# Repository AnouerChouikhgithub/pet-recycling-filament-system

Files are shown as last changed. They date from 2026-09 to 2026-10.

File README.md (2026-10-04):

# PET Plastic Recycling to 3D Printer Filament System

An Arduino-based system that turns PET plastic waste into usable 3D printer
filament through a custom-built extrusion control system. Independently
designed and developed as a solo project, currently in its 3rd hardware
iteration.

**Status:** Actively developed · 2024 – Present · Iterations V1 → V2 → V3 (V3.2 base assembly).

## Overview

The system controls extrusion temperature and filament feed rate in real time,
using closed-loop PID control and a microstepping stepper driver for consistent,
printable filament output. It is the machine side of the 3awedlou ecosystem:
the backend is the single backbone, and this firmware is the deterministic
controller that the ESP32 gateway will eventually network.

**Phases (as of this writing):**

| Phase | Description | Status |
|---|---|---|
| 1 | Arduino Mega direct control (Serial) | Done |
| 2 | ESP32 + TXS0108E serial gateway → MQTT | **Planned**, wired on bench, bench test pending |
| 3 | MQTT telemetry + command bridge to backend | Done (backend side, see repo README) |

This README documents the machine as it exists today (phase 1) and marks the
ESP32 gateway and the MQTT blade as planned. Hardware facts here come only from
the `.ino` and the files in `firmware/` and `cad/`; anything not present in the
code is marked `TODO(anouer)`.

## Repository tree (current)

```text
pet-recycling-filament-system/
├── firmware/
│   └── arduino-version/
│       └── arduino-version.ino          # Main Arduino firmware (PID control, stepper driving)
├── cad/
│   ├── PET-Recycling-Filament-System-Base - V3.2/
│   │   ├── PET-Recycling-Filament-System-Base 3.2.SLDPRT   # V3.2 base assembly, SolidWorks native
│   │   └── PET-Recycling-Filament-System-Base 3.2.STEP     # V3.2 base assembly, neutral STEP
│   └── 3D Printing/                  # Individual printable components (STEP)
│       ├── 2xBig-Separator.step
│       ├── 3xSmall-Separator.step
│       ├── 4xFixative.step
│       ├── Big-Gear-A.step
│       ├── Big-Gear-B.step
│       ├── Medium-Gear.step
│       ├── Medium-Separator.step
│       ├── Motor-Gear.step
│       ├── Motor-Separator.step
│       ├── Pulley.step
│       ├── Structure-A.step
│       └── Structure-B.step
├── docs/
│   ├── Schematic Diagram_bb.pdf      # Full breadboard / wiring schematic (Fritzing export)
└── README.md
```

> **Known stale paths in earlier READMEs:** the firmware is
> `firmware/arduino-version/arduino-version.ino` (NOT `firmware/code.ino`),
> the base assembly is `cad/PET-Recycling-Filament-System-Base - V3.2/`
> (NOT `cad/base-assembly/`). Keep this tree in mind when editing
> this document.

## Mechanical overview

The machine is a standalone PET extruder feeding a 3D printer filament path.
Base assembly and drivetrain are modeled in SolidWorks (`.SLDPRT`) plus a
neutral `.STEP` for interchange, and the printable cage/drivetrain parts are
provided as `.step` files in `cad/3D Printing/`.

| File / folder | What it is |
|---|---|
| `cad/PET-Recycling-Filament-System-Base - V3.2/` | Main structural assembly (V3.2), SolidWorks + STEP |
| `cad/3D Printing/*.step` | Individual 3D-printed parts: gears, separators, fixatives, pulleys, frame sections |
| `docs/Schematic Diagram_bb.pdf` | Full breadboard / wiring schematic |
| `firmware/arduino-version/arduino-version.ino` | Firmware source (single file) |

STEP files open in any CAD software (SolidWorks, Fusion 360, FreeCAD).

## Electronics overview

| Component | Role |
|---|---|
| Arduino Mega 2560 (with ATmega2560) | Main controller; keeps deterministic machine control |
| Thermistor (100 kΩ NTC, β=3950, nominal 25 °C @ 100 kΩ) | Temperature feedback for the PID loop, read on A7 |
| PWM-driven heater bridge (LPWM/RPWM) | Heating element actuation from the PID output |
| Stepper driver (TMC2209-class, 1/2–1/16 step) | Filament extrusion drive; microstepping selectable 1/2/4/8/16 via MS1–MS3 |
| Stepper motor (400 steps/rev full step) | Extrusion roller drive |
| Motor enable (R_EN/L_EN), Sleep/reset (SLEEP_RESET_PIN) | Driver enable + burst-mode wake |
| 12 V supply (heater + motor), 5 V (Arduino, thermistor) | Power rails; mains side is isolated from logic |

## Pin map (from `firmware/arduino-version/arduino-version.ino`)

Extracted verbatim from the sketch constants; nothing is inferred.

| Pin (Arduino name) | Constant name | Direction | Purpose | Source (`arduino-version.ino`) |
|---|---|---|---|---|
| 2 | `DIR_PIN` | OUTPUT | Motor direction (HIGH = reverse) | `setup()` / `loop()` |
| 3 | `STEP_PIN` | OUTPUT | Stepper step pulse | `loop()` |
| 4 | `SLEEP_RESET_PIN` | OUTPUT | Driver sleep/wake reset | `sleepDriver()` / `wakeDriver()` |
| 5 | `MS1_PIN` | OUTPUT | Microstepping select bit 1 | `setMicrostepping()` |
| 6 | `MS2_PIN` | OUTPUT | Microstepping select bit 2 | `setMicrostepping()` |
| 7 | `MS3_PIN` | OUTPUT | Microstepping select bit 3 | `setMicrostepping()` |
| 10 | `R_EN` | OUTPUT | H-bridge right side enable | `setHeaterPower()` / `heaterOff()` |
| 11 | `L_EN` | OUTPUT | H-bridge left side enable | `setHeaterPower()` / `heaterOff()` |
| 12 | `LPWM` | OUTPUT | Heater PWM (left H-bridge) | `setHeaterPower()` |
| 13 | `RPWM` | OUTPUT | Heater PWM (right H-bridge) | `setHeaterPower()` |
| A7 | `thermistorPin` | INPUT | Thermistor voltage divider ADC | `readingTemperature()` |

> `TODO(anouer): verify against the updated schematic` — the pin map above was
> read from the `.ino` only; the breadboard schematic (`docs/Schematic Diagram_bb.pdf`)
> has not been re-checked against the latest wired build.

## Firmware overview

### Control loop structure

`loop()` runs a tight, non-blocking cycle:

1. Read the thermistor (`readingTemperature()`).
2. Accelerate the motor: while `motorSpeed > MIN_MOTOR_DELAY`, decrement the
   step delay by `ACCELERATION_STEP` (5 µs per loop).
3. Drive the stepper: toggle `STEP_PIN` with `delayMicroseconds(motorSpeed)`
   and `delayMicroseconds(motorSpeed)` — a square wave whose period halves as
   speed ramps up.
4. Call `pidControl(temperature)`, which runs the PID on `millis()` deltas and
   scales the heater PWM.

The stepper timing loop is **independent** of the PID loop: stepping is
delay-based (not interrupt-driven), and PID runs in the same `loop()` pass.

### PID and units

* Target: `targetTemp = 245.0 °C` (PET extrusion).
* PID constants: `Kp = 5.0`, `Ki = 0.1`, `Kd = 30.0`.
* Output: `constrain(output, 0, 235)` → `setHeaterPower((int)output)` drives
  `LPWM` (left side enabled), `RPWM` holds at 0, both with `analogWrite` PWM.
* Temperature read over a 100 kΩ pull-up: `R = 100 kΩ`, β = 3950, nominal 25 °C,
  10-bit ADC, 5 V reference.

### Timing

* Stepper step time: `motorSpeed` in **microseconds** (starts 1000 µs, decrements
  toward `MIN_MOTOR_DELAY` = 200 µs, i.e. 5 k steps/s flat).
* PID runs on `millis()` deltas; `lastTime` seeded in `setup()`.

### Serial output

The firmware prints to `Serial` (baud 9600):

* `Serial.println("Setup complete. Driver awake, motor starting...")` in `setup()`.
* `Serial.print("Temp stable: ")` / `Serial.println(" °C")` when `|error| < 1.0`.
* `setMicrostepping()` prints the selected `1/n` mode.

No structured JSON, no `deviceAcknowledged`, and no command-response handshake
exist today. Serial is informational only.

### Safety status (as the code is written today)

| Check | Status |
|---|---|
| Over-temperature cutoff (hard >245 °C guard) | **Not implemented** as a hard cutoff. `pidControl` *clips* PID output to `constrain(output, 0, 235)` and turns the heater off if `temp > 330` or `temp == -273.15`; there is no independent over-temperature kill switch. |
| Thermistor fault handling | **Partially present.** `voltage <= 0` returns `-273.15`; `pidControl` then stops the heater. Clock drift / open-circuit is not explicitly guarded. |
| Watchdog | **Not used** in this sketch (no `WDT` enabled). |

> If a remote command path (ESP32/MQTT) is enabled before these guards exist,
> the machine could run past a safe temperature without software protection.
> Treat the firmware as **unprotected** until the remotes are re-verified
> (see the "planned" sections below).

## Planned: network gateway (ESP32 + TXS0108E)

```mermaid
flowchart LR
  Arduino_Mega -->|Serial1 TX/RX (pin 18/19)| TXS0108E
  TXS0108E -->|UART2| ESP32
  ESP32 -->|Wi-Fi| MQTT_Broker
  MQTT_Broker -->|commands| ESP32
  ESP32 -->|UART2| TXS0108E
  TXS0108E -->|Serial1 RX/TX| Arduino_Mega
```

**Status: PLANNED.** The physical link is wired on the bench (Arduino Mega
Serial1 pins 18/19 ↔ TXS0108E bidirectional level shifter ↔ ESP32 UART2), but
**is not yet tested**, and **the protocol is not yet defined**. No pin numbers
below are final — mark confirmed after the bench test.

| Signal | Source | Target | Note |
|---|---|---|---|
| Mega TX1 (pin 18) → TXS B1 → A1 → ESP32 RX | Firmware TX path | ESP32 UART2 RX | `TODO(anouer): confirm board model` |
| ESP32 TX → A2 → B2 → Mega RX1 (pin 19) | Firmware RX path | Mega Serial1 RX | |
| TXS VCCA | ESP32 3V3 | TXS0108E power | |
| TXS VCCB | Mega 5V | TXS0108E power | |
| TXS OE | 3V3 | TXS0108E bidirectional enable | |
| GND | common | TXS0108E / ESP32 / Mega | |
| ESP32 5V / VIN | **temporarily** from Mega 5V | ESP32 power | For bench only — a dedicated 12 V→5 V buck converter is planned |

> **Note:** the `ESP32` is `UART2 (GPIO16/17 on a classic DevKit) -
> TODO(anouer): confirm board model`. Do not treat GPIO16/17 as final until the
> dev kit is confirmed.

## Telemetry / command contract

The firmware today can **really** produce these telemetry fields over the
backend contract (`docs/mqtt-contract.md` in the backend repo):

* `temperature` — thermistor reading (real).
* `targetTemperature` — PID setpoint (real, 245 °C).
* `heaterState` — on/off derived from `analogWrite` duty.
* `motorState` — stepper enabled (real).
* `motorSpeed` — step rate, but **not** wired to firmware output yet
  (`0–10000 RPM` is the backend contract range; the firmware reports the µs
  step delay, which is the inverse).

**Not available today** (per the audit; verify against the code when it is
implemented):

* no fan/cooling channel,
* no filament-diameter sensor,
* no energy meter,
* no RPM output,
* no `recordedAt` (the firmware never timestamps samples),
* no events/beacons.

Telemetry identity comes from the **topic only** — a payload naming another
machine is rejected. Commands are versioned (v1) envelopes with
`commandId` (= `machine_command_audit.id`), `type`, `value`, `issuedAt`,
`expiresAt` (TTL 30 s default).

## Safety and handling

* **245 °C heater:** hot surfaces, fire risk, burns. Keep the machine unplugged
  until wiring is finished and verified.
* **Mains / 12 V:** live mains side separated from logic; use an isolation
  transformer where appropriate. Wear safety glasses when a run is active.
* **Recommendation:** a thermal fuse or cartridge fuse on the heater supply as
  hardware protection independent of software. **This is a recommendation,
  not implemented.**
* **Recommendation:** a dedicated 12 V→5 V buck converter for the ESP32 instead
  of the temporary Mega-5V feed.
* Never modify wiring while power is connected. Let the heater cool before
  probing.

## How to update this document

Revisit exactly these `TODO(anouer)` markers when the firmware and the
schematic change:

1. `TODO(anouer): verify against the updated schematic` — under the pin map table.
2. `TODO(anouer): confirm board model` — under the ESP32 UART2 / GPIO16/17 note.
3. `TODO(anouer): confirm bench test passed / protocol version` — under the
   "Planned: network gateway" section, when the bench test and protocol are
   finalised.
4. `TODO(anouer): update pin map` — if the sketch changes any pin define.
5. `TODO(anouer): telemetry fields` — when `motorSpeed`-like or new telemetry
   leaves the firmware.
6. `TODO(anouer): over-temperature cutoff` — when a hard cutoff is added to the
   firmware (the "Safety status" table must then reflect it).

## Related docs

* Backend README: https://github.com/AnouerChouikhgithub/PET-Recycling-Filament-System-Backend/blob/main/README.md
* MQTT contract (backend): https://github.com/AnouerChouikhgithub/PET-Recycling-Filament-System-Backend/blob/main/docs/mqtt-contract.md
* API contract (backend): https://github.com/AnouerChouikhgithub/PET-Recycling-Filament-System-Backend/blob/main/docs/api-contract.md

## License

TODO(anouer): no LICENSE file found in this repo — add one.

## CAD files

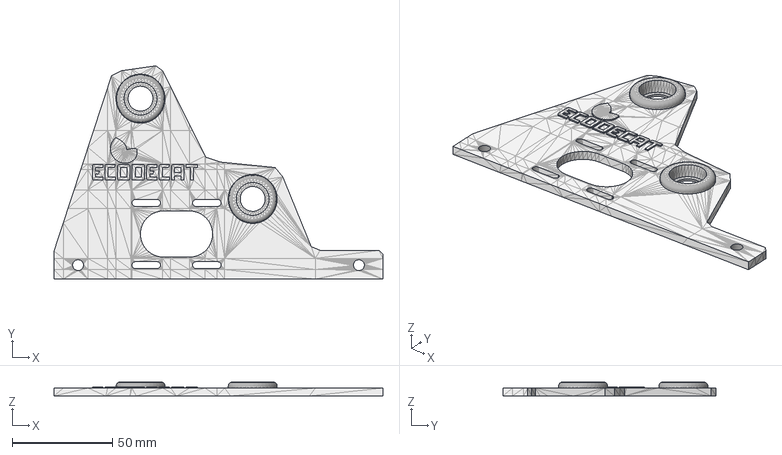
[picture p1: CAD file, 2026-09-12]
cad/3D Printing/Structure-A.step
164.0 x 106.3 x 7.00 mm

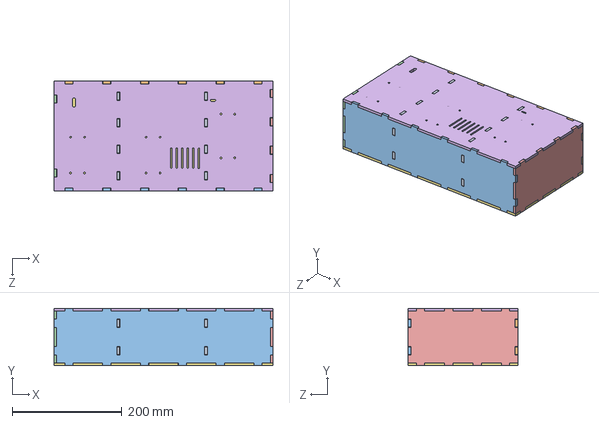
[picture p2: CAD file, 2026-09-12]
cad/PET-Recycling-Filament-System-Base - V3.2/PET-Recycling-Filament-System-Base 3.2.STEP
400.0 x 105.0 x 200.0 mm

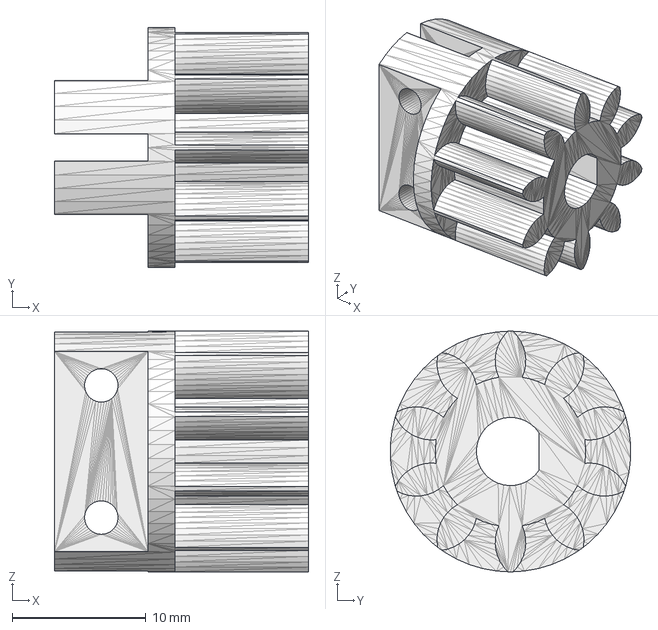
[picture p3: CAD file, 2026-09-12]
cad/3D Printing/Motor-Gear.step
19.0 x 18.0 x 18.0 mm

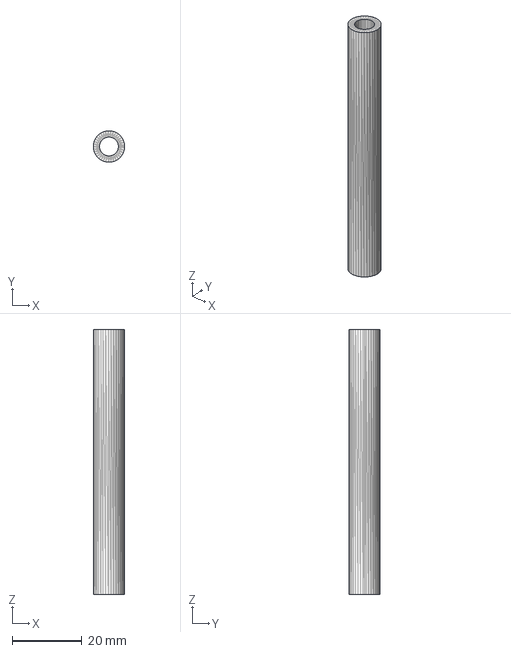
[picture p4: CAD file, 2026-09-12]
cad/3D Printing/2xBig-Separator.step
9.00 x 8.99 x 75.9 mm

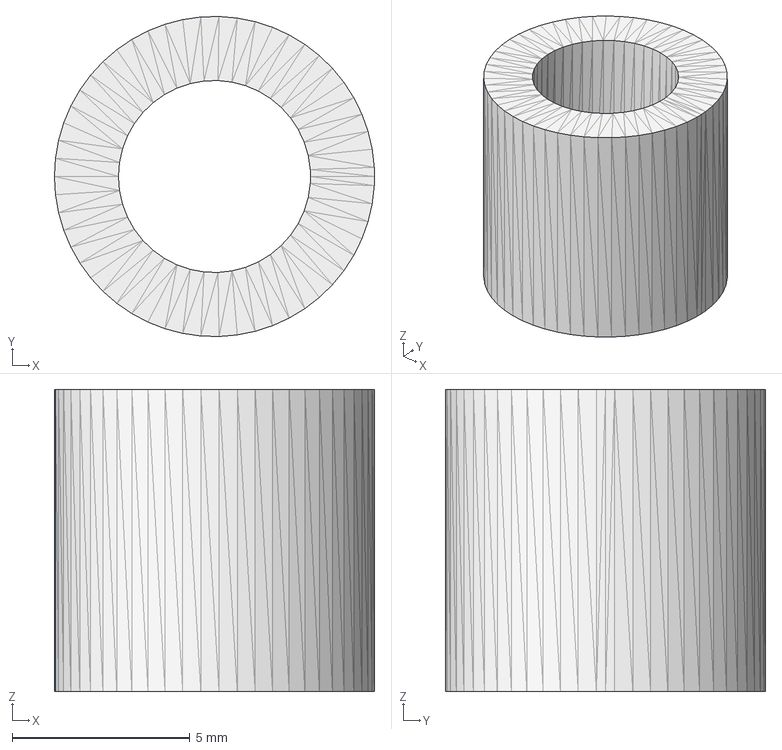
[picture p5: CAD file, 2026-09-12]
cad/3D Printing/3xSmall-Separator.step
9.00 x 9.00 x 8.50 mm

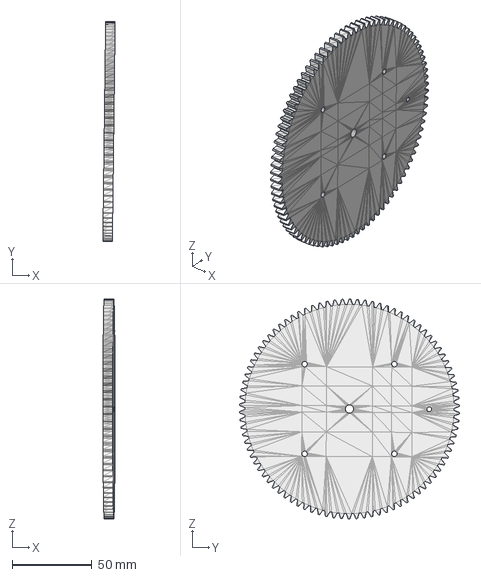
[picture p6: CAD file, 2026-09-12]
cad/3D Printing/Big-Gear-B.step
7.74 x 138.0 x 138.0 mm

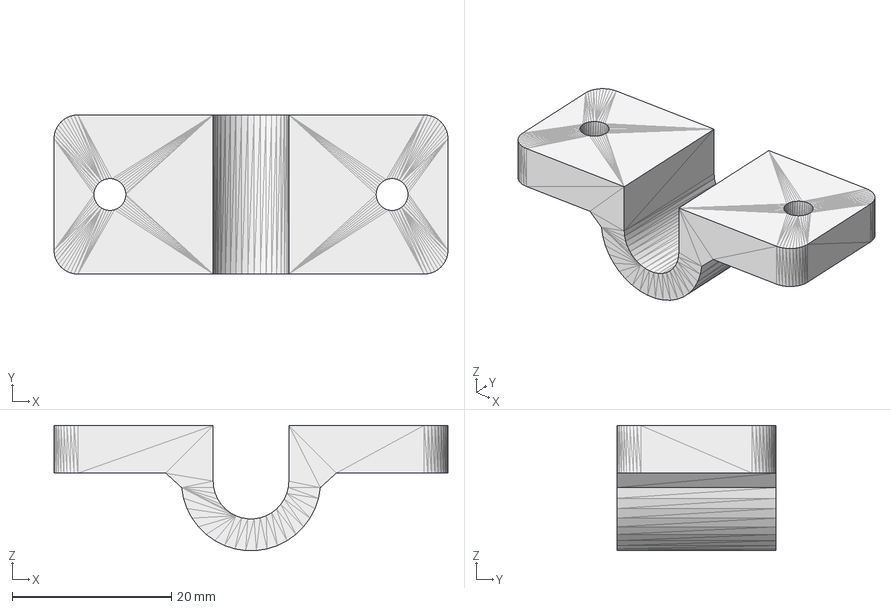
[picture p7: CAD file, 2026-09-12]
cad/3D Printing/4xFixative.step
49.5 x 20.0 x 15.7 mm

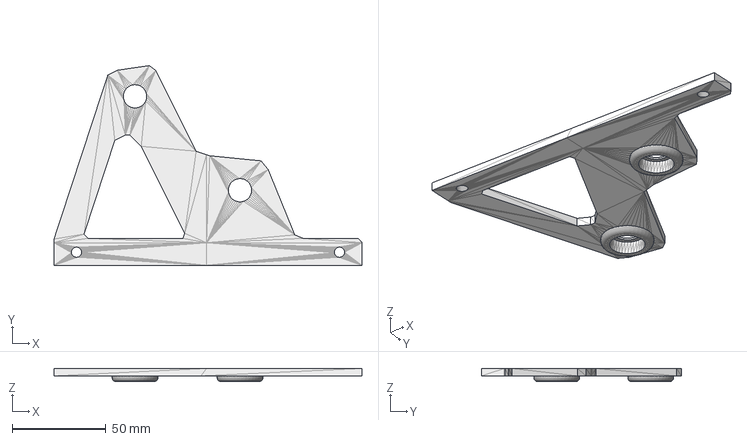
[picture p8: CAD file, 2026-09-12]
cad/3D Printing/Structure-B.step
164.0 x 106.3 x 7.00 mm

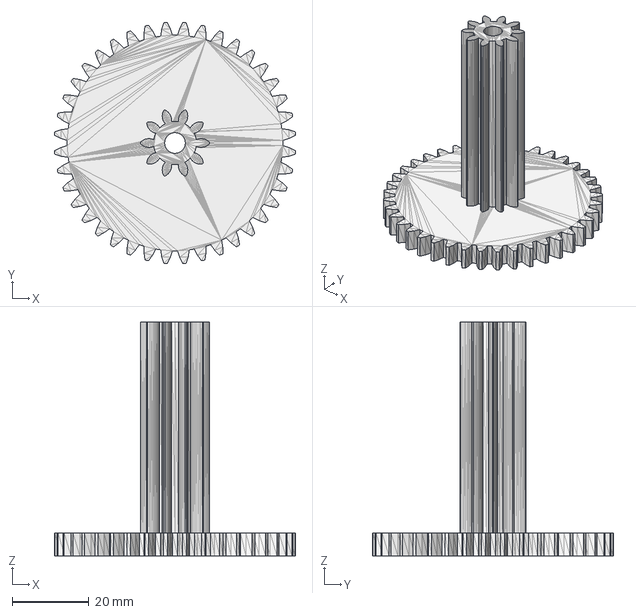
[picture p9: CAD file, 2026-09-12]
cad/3D Printing/Medium-Gear.step
62.9 x 62.9 x 61.0 mm

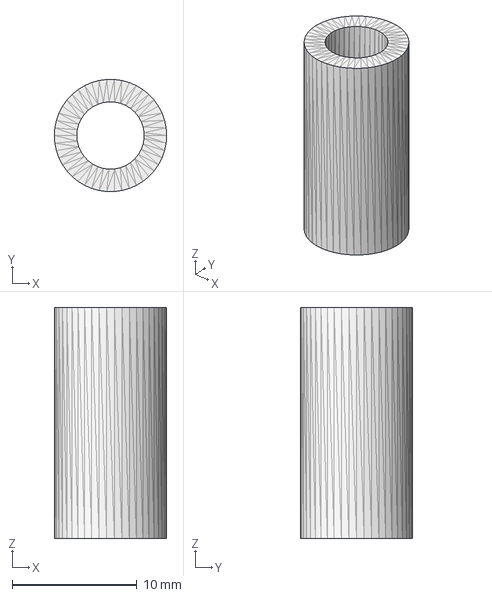
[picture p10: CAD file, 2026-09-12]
cad/3D Printing/Medium-Separator.step
9.00 x 8.98 x 18.5 mm

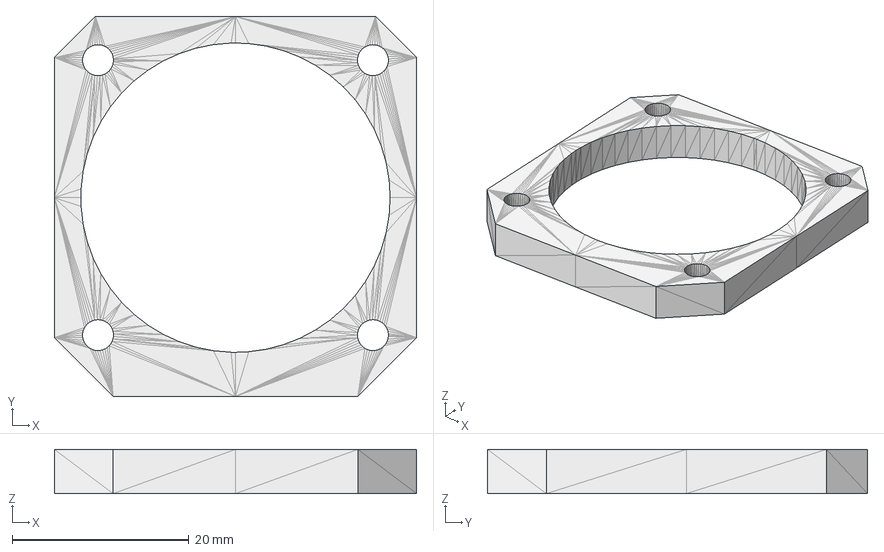
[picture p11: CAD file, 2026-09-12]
cad/3D Printing/Motor-Separator.step
41.0 x 43.0 x 5.00 mm

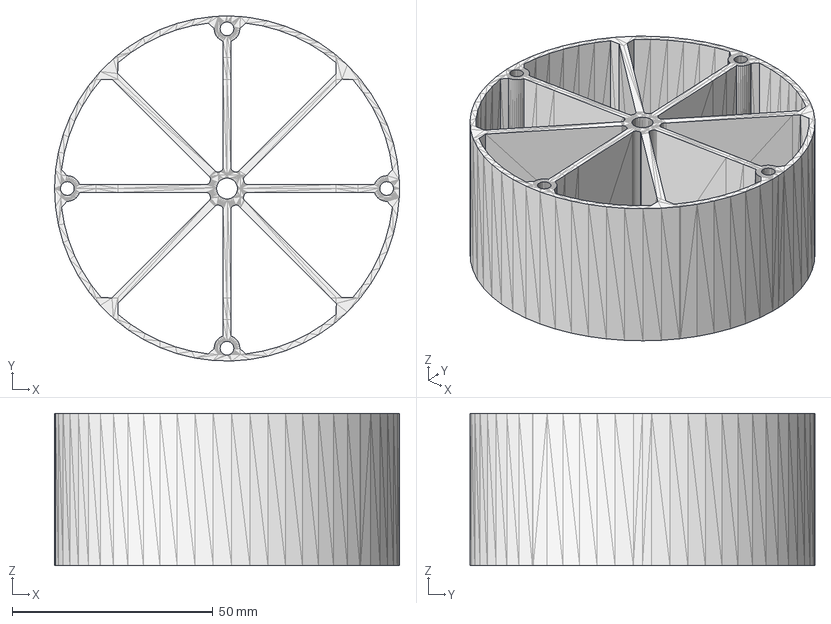
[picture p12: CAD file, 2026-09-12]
cad/3D Printing/Pulley.step
86.0 x 86.0 x 38.0 mm

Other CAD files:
cad/3D Printing/Big-Gear-A.step
cad/PET-Recycling-Filament-System-Base - V3.2/PET-Recycling-Filament-System-Base 3.2.SLDPRT

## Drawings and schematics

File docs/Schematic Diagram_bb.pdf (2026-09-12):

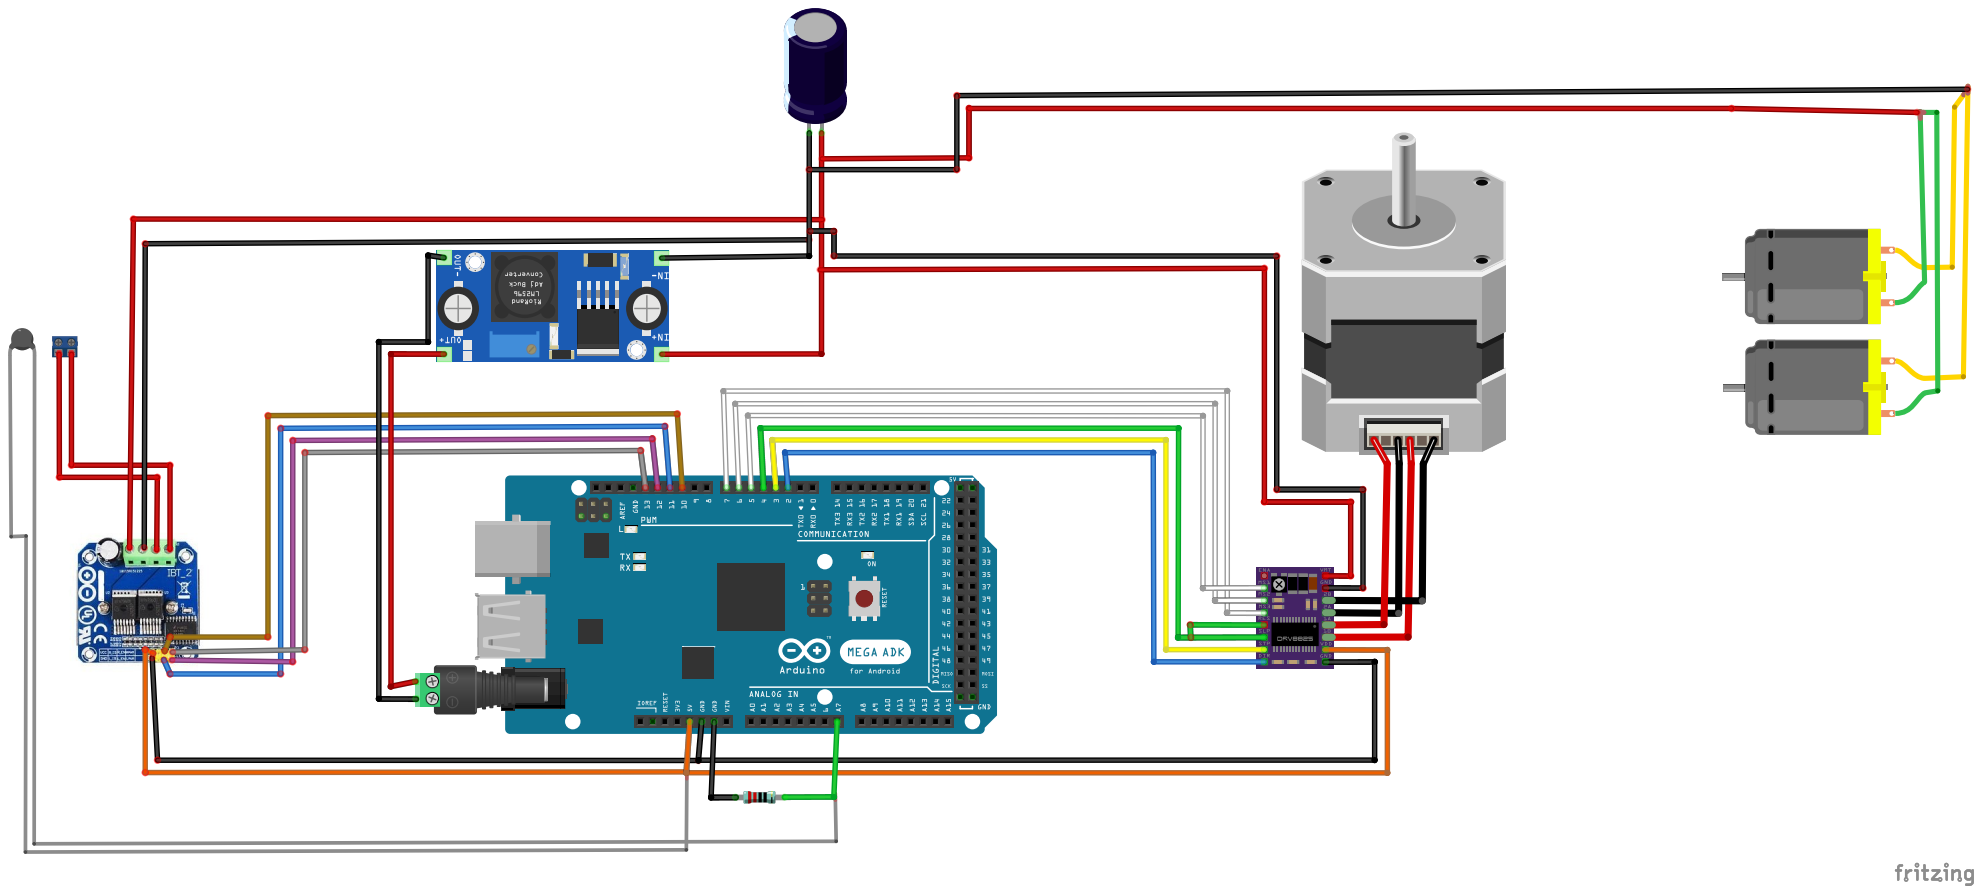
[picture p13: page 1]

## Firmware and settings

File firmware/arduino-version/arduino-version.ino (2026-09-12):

#include <math.h>

#define DIR_PIN 2
#define STEP_PIN 3
#define SLEEP_RESET_PIN 4

#define MS1_PIN 5
#define MS2_PIN 6
#define MS3_PIN 7

// Heater control pins
const int R_EN = 10;
const int L_EN = 11;
const int LPWM = 12;
const int RPWM = 13;
const int thermistorPin = A7;

// Thermistor constants
const float seriesResistor = 100000.0;
const float nominalResistance = 100000.0;
const float nominalTemperature = 25.0;
const float betaCoefficient = 3950.0;
const int adcMax = 1023;
const float vcc = 5.0;

// Target temperature
const float targetTemp = 245.0;

// PID Constants
float Kp = 5.0;
float Ki = 0.1;
float Kd = 30.0;

// PID Variables
float previousError = 0;
float integral = 0;
unsigned long lastTime = 0;

// Stepper Speed
int stepsPerRevolution = 400; // Updated by microstepping
int motorSpeed = 1000;        // Initial speed (microseconds)
const int MIN_MOTOR_DELAY = 200; // Fastest allowed step time (200µs = 5k steps/sec)
const int ACCELERATION_STEP = 5; // How much speed increases every loop

void setup() {
  pinMode(RPWM, OUTPUT);
  pinMode(LPWM, OUTPUT);
  pinMode(R_EN, OUTPUT);
  pinMode(L_EN, OUTPUT);

  pinMode(STEP_PIN, OUTPUT);
  pinMode(DIR_PIN, OUTPUT);
  pinMode(SLEEP_RESET_PIN, OUTPUT);

  pinMode(MS1_PIN, OUTPUT);
  pinMode(MS2_PIN, OUTPUT);
  pinMode(MS3_PIN, OUTPUT);

  Serial.begin(9600);

  setMicrostepping(2);      // Change microstepping as needed
  digitalWrite(SLEEP_RESET_PIN, HIGH); // Wake driver
  
  // Reverse motor direction
  digitalWrite(DIR_PIN, HIGH);         // Changed from HIGH to LOW to reverse direction

  Serial.println("Setup complete. Driver awake, motor starting...");

  heaterOff();
  lastTime = millis();
}

void loop() {
  float temperature = readingTemperature();

  // Accelerate the motor
  if (motorSpeed > MIN_MOTOR_DELAY) {
    motorSpeed -= ACCELERATION_STEP;
  }

  // Step the motor
  digitalWrite(STEP_PIN, HIGH);
  delayMicroseconds(motorSpeed);
  digitalWrite(STEP_PIN, LOW);
  delayMicroseconds(motorSpeed);

  // Temperature feedback and control
  pidControl(temperature);
}

// ---------------- HEATER CONTROL ----------------

void pidControl(float temp) {
  unsigned long currentTime = millis();
  float deltaTime = (currentTime - lastTime) / 1000.0;

  if (temp == -273.15 || temp > 330) {
    heaterOff();
    lastTime = currentTime;
    return;
  }

  float error = targetTemp - temp;

  if (abs(error) < 1.0) {
    Serial.print("Temp stable: ");
    Serial.print(temp);
    Serial.println(" °C");
  } else {
    integral += error * deltaTime;
    integral = constrain(integral, -100, 100);

    float derivative = (error - previousError) / deltaTime;
    float output = Kp * error + Ki * integral + Kd * derivative;

    output = constrain(output, 0, 235);
    setHeaterPower((int)output);

    previousError = error;
  }

  lastTime = currentTime;
}

float readingTemperature() {
  int adcValue = analogRead(thermistorPin);
  float voltage = adcValue * vcc / adcMax;

  if (voltage <= 0) return -273.15;

  float resistance = seriesResistor * (vcc / voltage - 1.0);
  float temp = resistance / nominalResistance;
  temp = log(temp);
  temp /= betaCoefficient;
  temp += 1.0 / (nominalTemperature + 273.15);
  temp = 1.0 / temp;
  temp -= 273.15;

  return temp;
}

void setHeaterPower(int pwmValue) {
  digitalWrite(R_EN, HIGH);
  digitalWrite(L_EN, HIGH);
  analogWrite(RPWM, 0);
  analogWrite(LPWM, pwmValue);
}

void heaterOff() {
  digitalWrite(R_EN, LOW);
  digitalWrite(L_EN, LOW);
  analogWrite(RPWM, 0);
  analogWrite(LPWM, 0);
}

// ---------------- STEPPER DRIVER CONTROL ----------------

void sleepDriver() {
  digitalWrite(SLEEP_RESET_PIN, LOW);
}

void wakeDriver() {
  digitalWrite(SLEEP_RESET_PIN, HIGH);
}

void setMicrostepping(int mode) {
  Serial.print("Setting microstepping to 1/");
  Serial.println(mode);

  switch (mode) {
    case 1:
      digitalWrite(MS1_PIN, LOW);
      digitalWrite(MS2_PIN, LOW);
      digitalWrite(MS3_PIN, LOW);
      stepsPerRevolution = 200;
      break;
    case 2:
      digitalWrite(MS1_PIN, HIGH);
      digitalWrite(MS2_PIN, LOW);
      digitalWrite(MS3_PIN, LOW);
      stepsPerRevolution = 400;
      break;
    case 4:
      digitalWrite(MS1_PIN, LOW);
      digitalWrite(MS2_PIN, HIGH);
      digitalWrite(MS3_PIN, LOW);
      stepsPerRevolution = 800;
      break;
    case 8:
      digitalWrite(MS1_PIN, HIGH);
      digitalWrite(MS2_PIN, HIGH);
      digitalWrite(MS3_PIN, LOW);
      stepsPerRevolution = 1600;
      break;
    case 16:
      digitalWrite(MS1_PIN, HIGH);
      digitalWrite(MS2_PIN, HIGH);
      digitalWrite(MS3_PIN, HIGH);
      stepsPerRevolution = 3200;
      break;
    default:
      Serial.println("Invalid microstepping mode, using full step.");
      digitalWrite(MS1_PIN, LOW);
      digitalWrite(MS2_PIN, LOW);
      digitalWrite(MS3_PIN, LOW);
      stepsPerRevolution = 200;
      break;
  }
}

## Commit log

2026-09-12 Initial commit: firmware, CAD files, and schematic
    [2xBig-Separator.step, 3xSmall-Separator.step, 4xFixative.step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]
2026-10-03 docs: overhaul README with pin map, contracts, and planned gateway
    Rewrite the hardware README with the real firmware/cad tree, the pin map
    extracted from firmware/arduino-version/arduino-version.ino, the PID/Serial
    behaviour, the telemetry/command contract, the planned ESP32+TXS gateway
    (Mermaid), safety notes, and a "How to update" TODO list.
2026-10-03 docs: rework README schematic path references
    Refer to the breadboard schematic by its real filename
    docs/Schematic Diagram_bb.pdf (the earlier README and commit referenced a
    stale/differently-cased name). Revert the schematic filename rename and fix
    the README paths instead.
